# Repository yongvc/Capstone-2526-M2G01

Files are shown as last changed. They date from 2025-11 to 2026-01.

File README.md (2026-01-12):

# Lemon Harvesting Robot Capstone Project

This project contains the complete source code and design files for an autonomous lemon harvesting robot. The system uses computer vision to detect lemons and controls a 3-axis gantry robot to harvest them automatically.

## System Architecture

```
+------------------+     Serial (115200)     +------------------+
|    Dashboard     | <------------------->   |   ESP32 MCU      |
|  (Python + CV)   |                         |   (Firmware)     |
+--------+---------+                         +--------+---------+
         |                                            |
         v                                            v
+------------------+                         +------------------+
| - Camera Capture |                         | - TMC2209 x3     |
| - Lemon Detection|                         | - Servos x4      |
| - Kalman Tracking|                         | - LEDs x4        |
| - Visual Servo   |                         | - Soft Limits    |
| - Harvest State  |                         | - I/O Expansion  |
+------------------+                         +------------------+
```

## Directory Structure

- **[`Dashboard/`](./Dashboard)**: The main control software
    - Python-based GUI (CustomTkinter) with dark theme
    - Real-time Computer Vision (OpenCV) for lemon detection
    - Kalman filter tracking for smooth, jitter-resistant control
    - Visual servo control with closed-loop feedback
    - Multi-threaded camera capture at 30 FPS
    - Auto-harvest mode for consecutive fruit harvesting
    - Serial communication with the firmware

- **[`Motor_Controller_Firmware/`](./Motor_Controller_Firmware)**: ESP32 firmware
    - Non-blocking stepper motor control with TMC2209 drivers
    - Trapezoidal acceleration profiles for smooth motion
    - Servo control for cutter and gripper mechanisms
    - 16+ serial commands for complete robot control
    - LED status indicators and soft limit protection

- **[`CAD/`](./CAD)**: Mechanical design files
    - SolidWorks assembly and part files
    - 3-axis gantry robot design

- **[`PCB/`](./PCB)**: Electronics design
    - Printed Circuit Board designs for motor driver integration

- **[`Report/`](./Report)**: Project documentation
    - Individual progress reports
    - Technical documentation

## Key Features

### Computer Vision
- **HSV Color Segmentation**: Tuned for yellow lemon detection (H: 10-30, S: 70-255, V: 40-255)
- **Watershed Algorithm**: Separates touching/overlapping lemons
- **Kalman Filter Tracking**: Smooth position estimation with velocity prediction
- **Persistent Object IDs**: Maintains tracking across frames even during temporary occlusion

### Motion Control
- **Non-Blocking Movement**: Firmware responds to commands during motion
- **Multi-Axis Simultaneous Control**: X, Y, Z axes move together for smooth tracking
- **Visual Servo Control**: Closed-loop approach using camera feedback
- **Trapezoidal Acceleration**: Smooth start/stop for precise positioning

### Harvesting Automation
- **State Machine Control**: IDLE -> APPROACHING -> CUTTING -> DEPOSITING -> RETURNING
- **Auto-Harvest Mode**: Consecutively harvest multiple lemons (configurable count)
- **Dynamic Speed Control**: Fast when far, slow and precise when close
- **Cutter Alignment Offset**: Configurable offset to compensate for camera-cutter distance

### User Interface
- **Real-time Video Display**: Embedded OpenCV window for 60 FPS performance
- **Manual Control Panel**: Direct stepper and servo control
- **Target Selection**: Click to select which lemon to harvest
- **Status Indicators**: FPS display, harvest state, axis positions
- **Mock Mode**: Test with pre-recorded video without hardware

## Getting Started

### Prerequisites
- Python 3.8+ with pip
- Arduino IDE or PlatformIO (for firmware upload)
- ESP32 development board
- USB webcam (640x480 recommended)

### Running the Dashboard

1. Navigate to the `Dashboard` directory:
    ```bash
    cd Dashboard
    ```

2. Create and activate virtual environment:
    ```bash
    python -m venv venv
    # Windows:
    .\venv\Scripts\activate
    # Linux/Mac:
    source venv/bin/activate
    ```

3. Install dependencies:
    ```bash
    pip install -r requirements.txt
    ```

4. Run the application:
    ```bash
    python main.py
    ```

### Uploading Firmware

1. Open `Motor_Controller_Firmware/Motor_Controller_Firmware.ino` in Arduino IDE
2. Install required libraries:
   - TMC2209 (for stepper driver communication)
3. Select ESP32 board and correct COM port
4. Upload to the ESP32

### Hardware Setup

1. Connect ESP32 to computer via USB
2. Connect webcam
3. Power on motor drivers (12-24V)
4. In Dashboard, select COM port and click "Connect"
5. Use "Set Zero" to establish home position
6. Start detection and select target lemon
7. Click "HARVEST" or use "AUTO" mode

## Serial Command Protocol

| Command | Format | Description |
|---|---|---|
| M | `M <axis> <dist> <speed> <accel>` | Non-blocking move (mm) |
| B | `B <axis> <dist> <speed> <accel>` | Blocking move (mm) |
| ? | `?` | Query position and busy state |
| G | `G` | Get axis limits configuration |
| H | `H` | Set current position as zero |
| R | `R` | Release/unlock steppers |
| ! | `!` | Emergency stop |
| S | `S <index> <angle>` | Set servo angle |
| C | `C <angle>` | Execute cut sequence |
| D | `D <angle>` | Execute drop sequence |

## Performance

- **Camera Capture**: 30 FPS (640x480)
- **Detection Rate**: 25-30 FPS
- **Display Rate**: 60 FPS (native OpenCV)
- **Serial Latency**: <50ms round-trip
- **Tracking Recovery**: Up to 3 seconds occlusion tolerance (90 frames)

## Technical Specifications

| Component | Specification |
|---|---|
| **Axis Travel** | X: 130mm, Y: 230mm, Z: 130mm |
| **Max Speed** | 500 mm/s |
| **Max Acceleration** | 6000 mm/s² |
| **Steps per mm** | 40 |
| **Camera Resolution** | 640 x 480 @ 30 FPS |
| **Detection HSV** | H: 10-30, S: 70-255, V: 40-255 |
| **Kalman Filter** | process_noise=0.5, measurement_noise=1.0 |
| **Visual Servo Gain** | 0.10 mm/pixel |
| **Area Threshold** | 23000 px² (triggers cutting) |
| **Approach Threshold** | 25 px (alignment tolerance) |
| **Cutter Offset** | Z: 50mm, Y: 60mm |
| **Total Cost** | RM 608 |

## Authors

- **M2G01 Team** - UTM Capstone Project 2025/2026

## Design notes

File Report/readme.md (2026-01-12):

# Project Reports & Documentation

This directory contains project documentation and reports for the Lemon Harvesting Robot Capstone Project.

## Documents

| File | Description |
|---|---|
| `Technical_Report.txt` | Complete technical report with system design, implementation details, and team contributions |
| `Discussion Note (W1-W12).pdf` | Weekly discussion notes and meeting records |
| `Rules&RubricLime Harvesting Robot Challenge v9.pdf` | Competition rules and evaluation rubric |
| `System Block Diagram.png` | High-level system architecture diagram |

## Technical Report Summary

The Technical Report (`Technical_Report.txt`) contains:

1. **Introduction** - Problem statement and objectives
2. **Literature Review** - Existing solutions and market analysis
3. **Methodology** - CDIO framework and development approach
4. **System Design** - Hardware and software architecture
5. **Implementation** - Detailed component development
6. **Testing & Results** - Performance evaluation
7. **Future Works** - Planned improvements
8. **Conclusion** - Project outcomes and cost analysis
9. **Team Contributions** - Individual member contributions with code references

### Key Technical Specifications

| Parameter | Value |
|---|---|
| HSV Detection | H: 10-30, S: 70-255, V: 40-255 |
| Kalman Filter | process_noise=0.5, measurement_noise=1.0 |
| Area Threshold | 23000 px² |
| Visual Servo Gain | 0.10 mm/pixel |
| Axis Travel | X: 130mm, Y: 230mm, Z: 130mm |
| Max Speed | 500 mm/s |
| Steps per mm | 40 |
| Serial Baud | 115200 |
| Total Cost | RM 608 |

## Team Members

| Member | Responsibility |
|---|---|
| M1 - Yasser Ashraf | Vision System & Lemon Detection |
| M2 - Afifah Maisarah | User Interface & Dashboard |
| M3 - Chew Yong Jun | Mechanical Design & Assembly |
| M4 - Yong Vin Cent | Firmware & Motor Controller |

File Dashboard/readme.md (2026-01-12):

# Robot Dashboard

The Dashboard is the central control interface for the Lemon Harvesting Robot. It provides real-time camera visualization, computer vision-based lemon detection with Kalman tracking, and automated harvesting control through a visual servo system.

## Architecture

```
main.py (DashboardApp)
    |
    +-- camera.py
    |   +-- CameraThread      (30 FPS capture, triple-buffered)
    |   +-- DetectionThread   (async detection, Kalman tracking)
    |   +-- FrameBuffer       (zero-copy frame delivery)
    |
    +-- harvester.py
    |   +-- HarvestingStateMachine (visual servo control)
    |   +-- HarvestState enum (IDLE, APPROACHING, CUTTING, DEPOSITING, RETURNING)
    |
    +-- embedded_cv_display.py
    |   +-- EmbeddedCVDisplay (native OpenCV in Tkinter)
    |
    +-- LemonDetector/
        +-- detect.py         (HSV + Watershed detection)
        +-- kalman_tracker.py (Kalman filter tracking)
```

## Features

### Real-time Computer Vision
- **HSV Color Segmentation**: Optimized for yellow lemon detection
- **Watershed Algorithm**: Separates touching/overlapping fruits
- **Multi-Object Tracking**: Persistent IDs across frames
- **Kalman Filter Smoothing**: Reduces jitter, predicts during occlusion

### Visual Servo Control
- **Closed-Loop Approach**: Uses camera feedback for alignment
- **Multi-Axis Simultaneous Movement**: X, Y, Z move together for smooth tracking
- **Dynamic Speed Control**: Fast when far, slow when close for precision
- **Area-Based Distance Estimation**: Triggers cutting when lemon is close enough

### Harvesting Automation
- **Single Target Mode**: Select and harvest one lemon
- **Auto-Harvest Mode**: Consecutively harvest 3 lemons (configurable)
- **State Machine**: IDLE -> APPROACHING -> CUTTING -> DEPOSITING -> RETURNING
- **Jitter Tolerance**: Maintains tracking during camera vibration (up to 3s occlusion)

### User Interface
- **Dark Theme**: Modern CustomTkinter interface
- **Embedded Video Display**: Native OpenCV rendering at 60 FPS
- **Manual Controls**: Direct stepper and servo control
- **Status Display**: FPS, harvest state, detected lemons list
- **Center Offset**: Calibrate cutter position relative to camera

## Module Documentation

### main.py - DashboardApp

The main application class that integrates all components:

```python
class DashboardApp(ctk.CTk):
    def __init__(self):
        # Initialize camera and detection threads
        self.camera_thread = CameraThread(mock_mode=False, target_fps=30)
        self.detection_thread = DetectionThread(self.camera_thread.frame_buffer)
        
        # Initialize harvesting state machine
        self.harvester = HarvestingStateMachine(self)
        
        # Setup UI components
        self.setup_controls()
```

Key methods:
- `toggle_connection()`: Connect/disconnect serial port
- `update_camera_ui()`: Main UI update loop (33ms interval)
- `start_harvest()`: Begin harvesting selected lemon
- `start_auto_harvest()`: Begin auto-harvest mode
- `send_command(cmd)`: Send command to firmware

### camera.py - Multi-Threaded Capture

**CameraThread**: Captures frames at target FPS
```python
class CameraThread(threading.Thread):
    def __init__(self, mock_mode=False, mock_path="mock_lemon.mp4", target_fps=30):
        self.frame_buffer = FrameBuffer()  # Triple-buffered output
```

**DetectionThread**: Runs detection asynchronously
```python
class DetectionThread(threading.Thread):
    def __init__(self, frame_buffer):
        self.detector = LemonDetector(use_kalman=True, responsive_tracking=True)
    
    def get_latest(self):
        return self._latest_frame, list(self._latest_lemons)
```

**FrameBuffer**: Zero-copy frame delivery
```python
class FrameBuffer:
    def write(self, frame): # Producer (camera thread)
    def read(self):         # Consumer (detection thread)
    def wait_for_frame(self, timeout=0.1):
```

### harvester.py - Harvesting State Machine

Visual servo control with multi-axis simultaneous movement:

```python
class HarvestingStateMachine:
    # Key parameters (tunable)
    self.area_threshold = 23000       # pixels^2 to trigger cutting
    self.approach_threshold = 25      # pixels alignment tolerance
    self.visual_servo_gain = 0.10     # mm per pixel error
    self.forward_speed = 20.0         # mm per forward step
    self.max_correction = 15.0        # max mm per correction
    self._max_frames_lost = 90        # 3 seconds at 30fps before abort
    
    # Speed settings
    self.approach_speed = 30          # mm/s for X/Z corrections
    self.forward_approach_speed = 80  # mm/s for Y forward
    self.fast_speed = 200             # mm/s for deposit/return
    
    # Cutter offsets
    self.cutting_z_offset = 50        # mm (cutter below camera)
    self.cutting_y_offset = 60        # mm (cutter behind camera)
```

State transitions:
1. **IDLE**: Waiting for harvest command
2. **APPROACHING**: Visual servo approach using Kalman-smoothed positions
3. **CUTTING**: Move to cutter offset, execute cut sequence
4. **DEPOSITING**: Move to basket, execute drop sequence
5. **RETURNING**: Return to home position

### LemonDetector/detect.py - Detection Pipeline

HSV + Watershed detection with tracking:

```python
class LemonDetector:
    # HSV ranges (tuned for yellow lemons)
    FIXED_H_MIN, FIXED_H_MAX = 10, 30
    FIXED_S_MIN, FIXED_S_MAX = 70, 255
    FIXED_V_MIN, FIXED_V_MAX = 40, 255
    
    # Tracking parameters
    self.maxDisappeared = 1000        # frames before deregistering
    self.maxMatchDistance = 300       # pixels for ID matching
```

Detection pipeline:
1. Gaussian blur (11x11)
2. HSV color thresholding
3. Morphological opening + dilation
4. Distance transform + watershed
5. Contour analysis (filter by area > 1000, circularity > 0.3)
6. Multi-object tracking with Kalman filtering

### LemonDetector/kalman_tracker.py - Smooth Tracking

Constant velocity Kalman filter for each tracked object:

```python
class KalmanTracker:
    # State: [x, y, vx, vy]
    # Responsive mode: process_noise=0.5, measurement_noise=1.0
    
    def predict(self):      # Predict next position
    def update(self, pos):  # Correct with measurement
    def get_position(self): # Get smoothed position
    def get_velocity(self): # Get velocity estimate
```

Benefits:
- Smooths detection jitter from camera vibration
- Predicts position during temporary occlusion (up to 60 frames / 2s in Kalman, 90 frames / 3s in harvester)
- Provides velocity for predictive control

### embedded_cv_display.py - Native OpenCV Display

Embeds OpenCV window inside Tkinter for native rendering performance:

```python
class EmbeddedCVDisplay:
    def _create_and_embed(self):
        # Create OpenCV window
        cv2.namedWindow(self.window_name, cv2.WINDOW_NORMAL)
        
        # Reparent using Windows API
        win32gui.SetParent(self.cv_hwnd, tk_hwnd)
    
    def update(self, frame):
        cv2.imshow(self.window_name, frame)  # Native rendering
```

Performance: ~60 FPS vs ~15 FPS with PIL/ImageTk conversion.

## Setup

1. Navigate to this directory:
    ```bash
    cd Dashboard
    ```

2. Create virtual environment:
    ```bash
    python -m venv venv
    .\venv\Scripts\activate  # Windows
    ```

3. Install dependencies:
    ```bash
    pip install -r requirements.txt
    ```

## Usage

Run the main application:
```bash
python main.py
```

### Controls

| Control | Description |
|---|---|
| Connect | Connect to ESP32 via serial port |
| HARVEST | Harvest the selected (highlighted) lemon |
| AUTO (3) | Automatically harvest 3 lemons consecutively |
| ABORT | Stop current harvest and return home |
| Move | Move selected axis by distance/speed/accel |
| Center | Move all axes to home position |
| Set Zero | Set current position as 0,0,0 |
| Unlock | Disable steppers for manual movement |
| Cut/Drop | Test cutter and gripper mechanisms |
| EMERGENCY STOP | Immediately stop all motors |

### Tuning Detection

For different lighting conditions, adjust HSV values in `LemonDetector/detect.py`:
```python
self.FIXED_H_MIN = 10   # Hue minimum (yellow starts ~10)
self.FIXED_H_MAX = 30   # Hue maximum (yellow ends ~35)
self.FIXED_S_MIN = 70   # Saturation minimum (filter out white)
self.FIXED_V_MIN = 40   # Value minimum (filter out dark)
```

Enable tuning mode to use trackbars:
```python
detector = LemonDetector(tuning_mode=True)
```

### Calibrating Center Offset

The cutter is physically offset from the camera. Use the Offset X/Y controls to compensate:
1. Position a lemon at the camera center (crosshair)
2. Observe where the cutter actually aligns
3. Enter offset values to shift the target point
4. Click "Apply" to update

## Key Files

| File | Description |
|---|---|
| `main.py` | Main application, UI, serial communication |
| `camera.py` | Multi-threaded camera capture and detection |
| `harvester.py` | Harvesting state machine, visual servo control |
| `embedded_cv_display.py` | Native OpenCV window embedding |
| `LemonDetector/detect.py` | Computer vision detection pipeline |
| `LemonDetector/kalman_tracker.py` | Kalman filter for smooth tracking |
| `mock_lemon.mp4` | Sample video for Mock Mode testing |
| `requirements.txt` | Python dependencies |

## Dependencies

- `customtkinter` - Modern Tkinter widgets
- `opencv-python` - Computer vision
- `numpy` - Numerical operations
- `pyserial` - Serial communication
- `pywin32` - Windows API for embedded display (Windows only)

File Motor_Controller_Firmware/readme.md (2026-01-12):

# Motor Controller Firmware

This directory contains the ESP32 firmware for the robot's motor controller. It provides non-blocking stepper motor control with TMC2209 drivers, servo control for the harvesting mechanism, and a comprehensive serial command protocol.

## Architecture

```
Motor_Controller_Firmware.ino (Main Loop)
    |
    +-- StepperController.cpp/h
    |   - Non-blocking movement with trapezoidal acceleration
    |   - TMC2209 UART driver control
    |   - Position tracking in mm (40 steps/mm)
    |   - Soft limits with min/max per axis
    |   - Move completion detection (checkCompleted)
    |
    +-- ServoController.cpp/h
    |   - PWM control for 4 servos
    |   - Angle-based positioning (0-180 degrees)
    |   - Used for cutter (servos 0,1) and gripper (servo 2)
    |
    +-- LEDController.cpp/h
    |   - 4 status LEDs with non-blocking blink
    |   - LED 0: Heartbeat, LED 1: Moving, LED 2: Home, LED 3: Limit warning
    |
    +-- IOController.cpp/h
    |   - Digital input reading
    |   - Reserved for limit switch inputs (optional hardware)
    |
    +-- Config.h
    |   - Serial baud rate, timing constants
    |
    +-- PinMap.h
        - Pin assignments for ESP32
```

## Features

### Non-Blocking Motor Control
- Motors move without blocking serial command processing
- `M` command returns immediately, firmware sends `DONE <axis>` when complete
- Enables visual servo control with real-time position updates

### Trapezoidal Acceleration
- Smooth acceleration/deceleration profiles
- Configurable max speed (500 mm/s) and acceleration (6000 mm/s^2)
- Per-axis motion state tracking

### Soft Limits (Software-Based)
- Configurable min/max limits per axis
- Prevents over-travel using software position tracking
- No physical limit switches required (optional hardware)
- Limits sent to Dashboard via `G` command

### LED Status Indicators
| LED | Function |
|-----|---|
| 0 | Heartbeat (continuous blink) |
| 1 | Moving (ON when any axis active) |
| 2 | Home (ON when all axes at 0,0,0) |
| 3 | Limit warning (fast blink when at limit) |

## Serial Command Protocol

**Baud Rate**: 115200

### Motor Commands

| Command | Format | Response | Description |
|---|---|---|---|
| M | `M <axis> <dist> <speed> <accel>` | `OK M` then `DONE <axis>` | Non-blocking move |
| B | `B <axis> <dist> <speed> <accel>` | `BUSY M` then `DONE <axis>` | Blocking move |
| ? | `?` | `POS x y z` + `BUSY 0 0 0` | Query position/status |
| G | `G` | `LIMITS x y z` | Get axis limits |
| H | `H` | `OK H` | Set current position as 0,0,0 |
| R | `R` | `OK R` | Release/unlock steppers |
| P | `P <axis> <pos>` | `OK P` | Set axis position value |
| W | `W <axis> <min> <max>` | `OK W` | Set soft limits |
| E | `E <0\|1>` | `OK E` | Enable/disable limits |
| ! | `!` | `STOP` | Emergency stop all axes |

### Servo Commands

| Command | Format | Response | Description |
|---|---|---|---|
| S | `S <index> <angle>` | `OK S` | Set servo angle (0-180) |
| C | `C <angle>` | `BUSY C` then `OK C` | Cut sequence (servos 0,1) |
| D | `D <angle>` | `BUSY D` then `OK D` | Drop sequence (servo 2) |

### Utility Commands

| Command | Format | Response | Description |
|---|---|---|---|
| L | `L <index> <state>` | `OK L` | Control LED on/off |
| I | `I <index>` | `IO <index> <val>` | Read digital input |
| Z | `Z <axis>` | `LIMIT <axis> <val>` | Read limit switch (optional) |

### Axis Numbering
- 0 = X axis (left-right)
- 1 = Y axis (forward-backward)  
- 2 = Z axis (up-down)

### Response Messages
- `OK <cmd>` - Command accepted
- `BUSY <cmd>` - Command in progress (blocking)
- `DONE <axis>` - Movement complete on axis
- `STOP` - Emergency stop executed
- `POS x y z` - Current position in mm
- `BUSY 0 0 0` - Busy state per axis (0=idle, 1=moving)
- `LIMITS x y z` - Max limits per axis in mm

## Cut Sequence Details

The `C <angle>` command executes a triple-cut sequence:
1. Servos 0,1 move to scissor position (90-angle, 90+angle)
2. Wait 300ms
3. Return to neutral (90, 90)
4. Repeat 3 times for reliable cutting
5. Send `OK C`

## Drop Sequence Details

The `D <angle>` command executes:
1. Servo 2 moves to release position (90-angle)
2. Wait 1000ms for fruit to fall
3. Return to neutral (90)
4. Send `OK D`

## Configuration

### StepperController.h Constants
```cpp
static constexpr float STEPS_PER_MM = 40.0;      // Steps per millimeter
static constexpr float MAX_SPEED_MM_S = 500.0;   // Max speed mm/s
static constexpr float MAX_ACCEL_MM_S2 = 6000.0; // Max acceleration mm/s^2
```

### Default Axis Limits
- X: 0 to 130 mm
- Y: 0 to 230 mm
- Z: 0 to 130 mm

## Setup

1. Open `Motor_Controller_Firmware.ino` in Arduino IDE

2. Install required libraries:
   - **TMC2209** (for stepper driver UART control)

3. Select board:
   - Board: ESP32 Dev Module (or your specific ESP32 variant)
   - Upload Speed: 921600
   - CPU Frequency: 240MHz

4. Upload the firmware

5. Open Serial Monitor at 115200 baud to test:
   ```
   G           # Get limits
   ?           # Query position
   M 0 50 100 200   # Move X axis 50mm
   ```

## Pin Configuration

### GPIO Assignments (from PinMap.h)

| Function | GPIO Pins |
|---|---|
| **LEDs** | 39, 40, 41, 42 |
| **Servos** | 9, 10, 11, 12 |
| **Stepper Enable** | 20 (shared, active-LOW) |
| **X-axis** | Step: 8, Dir: 18 |
| **Y-axis** | Step: 17, Dir: 16 |
| **Z-axis** | Step: 15, Dir: 7 |
| **TMC2209 UART** | RX: 2, TX: 1 |
| **Digital I/O** | 13, 14, 21, 47, 48 |

### Config.h Constants

| Parameter | Value |
|---|---|
| Serial Baud Rate | 115200 |
| TMC2209 R_SENSE | 0.11 ohms |
| Servo PWM Min | 500 us |
| Servo PWM Max | 2400 us |
| LED Blink Interval | 500 ms |

## Integration with Dashboard

The Dashboard Python application communicates with this firmware:

1. Dashboard connects to COM port at 115200 baud
2. Queries configuration: `G` command
3. Queries position: `?` command  
4. Sends move commands: `M <axis> <dist> <speed> <accel>`
5. Waits for `DONE <axis>` response
6. Executes cut/drop sequences: `C <angle>`, `D <angle>`

The non-blocking `M` command allows the Dashboard to send corrective movements during visual servo approach without waiting for previous moves to complete.

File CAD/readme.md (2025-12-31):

# Mechanical Design (CAD)

This directory contains the SolidWorks (`.SLDPRT`, `.SLDASM`) files for the Lemon Harvesting Robot.

## Structure

The main assembly file is located in `final assembly 1/`:
- **Main Assembly**: `final assembly 1.SLDASM`

### Key Components
- **Arm Mechanism**: `Arm.SLDASM` - The robotic arm structure for connecting the chassis to the end effector.
- **End Effector/Gripper**:
    - `CutterHolder.SLDPRT`
    - `UScissor.SLDPRT`
    - `ServoScissorHolder.SLDPRT`
- **Chassis/Base**: `Base.SLDPRT`, `Cam Base.SLDPRT`
- **Drive System**: Stepper motors (`Assem1_stepper_motor.SLDASM`), pulleys, and belts.
- **Camera Mount**: `Camera Casing.SLDPRT`, `C260 WebCam Assembly.SLDASM`

## Usage
Open `final assembly 1/final assembly 1.SLDASM` in SolidWorks to view the complete robot assembly.

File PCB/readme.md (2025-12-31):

# PCB Design

This directory contains the files related to the custom Printed Circuit Board (PCB) designed for the robot.

## Contents
- **Gerber Files**: `Capstone Agriculture Gerber_PCB1_2025-11-11.zip` - The production files to send to a PCB manufacturer (e.g., JLCPCB).
- **Interactive BOM**: `InteractiveBOM_PCB1_2025-11-29.html` - An interactive HTML file to assist with component placement and soldering. Open this in a web browser.
- **Schematic**: `SCH_Schematic1_1-P1_2025-11-21.png` - Image of the circuit schematic.

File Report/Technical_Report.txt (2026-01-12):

Automated Lemon Harvesting Robot

Yasser Ashraf Aly Abdelsattar Youssef, Afifah Maisarah binti Asmadi, Chew Yong Jun, Yong Vin Cent, Tn Hj Mohd Shukri Abdul Manaf
Universiti Teknologi Malaysia, Malaysia

================================================================================
ABSTRACT
================================================================================

The agricultural industry faces increasing challenges due to labor shortages and the need for precision in fruit harvesting, particularly for citrus crops like lemons which require careful handling. This project addresses these challenges through the development of an automated lemon harvesting robot designed to autonomously identify, reach, and collect ripe fruit. The system utilizes a three-axis (XYZ) linear slider mechanism driven by NEMA 17 stepper motors and timing belts for precise spatial positioning. At the core of the hardware is a customized PCB integrating an ESP32 microcontroller, buck converters, stepper motor drivers, and servo controllers to manage power and motion. For fruit identification, the system employs an OpenCV-based computer vision algorithm that performs color segmentation and coordinate detection to distinguish ripe lemons from the canopy. Once a target is identified, a central Python script orchestrates the harvesting sequence, calculating trajectories and transmitting specific motion commands to the embedded controller. The controller then maneuvers a specialized end-effector to cut and catch the lemon before placing it into a collection basket. A dedicated user interface provides real-time monitoring of lemon ripeness, lemon positions, and system status. Preliminary results indicate a fruit detection success rate of 90% and a positioning accuracy of within 10mm. This study demonstrates that low-cost, high-precision robotics can effectively digitize orchard management, offering a scalable solution to agricultural labor shortages and improving overall harvest yield.

Keywords: Agricultural Robotics, Computer Vision, Automated Harvesting, ESP32 Microcontroller, Precision Agriculture

================================================================================
1. CONCEIVE
================================================================================

1.1 Background Introduction

The target users for this project are fruit farmers, especially those who grow citrus fruits like lemons. These farmers face many problems when it comes to harvesting their crops.

The first major problem is shortage of workers. Farm work is tiring and the harvesting season only lasts for a few months each year. This makes it hard to find people who want to do this job. Big farms sometimes need 50 to 60 workers just to harvest all the fruit, which costs a lot of money.

Another problem is worker safety. The traditional way of picking fruit involves climbing up ladders to reach fruit on tall trees. Workers can fall and get injured. New workers who do not have experience often damage the fruit because they do not know the proper way to handle it.

The quality of harvest is also affected by using manual labour. How good the harvest turns out depends on how skilled the worker is. When workers use gloves and clippers, they may not cut the stem at the right place or they may squeeze the fruit too hard. This damages the fruit and makes it harder to sell.

Lastly, the whole harvesting process is still done by hand, from picking the fruit to sorting them by quality. This takes a lot of time and the farm cannot process as many fruit as they could with machines.

These problems show why there is a need for a robot that can find ripe fruit, reach it accurately, and pick it without causing damage. This would help farmers save money on workers and get better quality fruit.

1.2 End-user Input Data

To understand what farmers really need, our team prepared a questionnaire and interviewed real farmers. We asked the following questions:

1. How do you currently harvest fruits or crops from the trees?
2. What are the biggest challenges or difficulties you face during harvesting?
3. Which part of the harvesting process takes the most time or effort?
4. Are there any safety or injury risks that come with harvesting?
5. How many workers are usually needed to harvest one tree or a section of the farm?
6. Have you ever tried or seen harvesting machines or tools before? If yes, what did you like or dislike about them?
7. What features would be most valuable to you in a harvesting solution?
8. What kind of terrain and tree height should the solution be able to handle?
9. How much are you willing to invest or spend on technology that can make harvesting easier or faster?
10. Would you be open to testing or giving feedback on a prototype harvesting solution?

We conducted interviews with several farmers and plant sellers. From these discussions, each team member extracted key data points.

Yasser found that farmers are interested in features like camera systems for fruit counting, smart sensors to detect fruit size and colour, lightweight harvesting robot arms, and drone monitoring for crop health.

Chew Yong Jun learned that farmers use equipment with cameras, pruners and nets. They face challenges with labour availability and weather. There is interest in automated ripeness detection based on colour, firmness, and average fruit size. Some farms use open fertigation systems with IoT integration.

Vin Cent discovered that harvesting is done manually with gloves and clippers. The main challenges are labour availability and weather. Farms need 50 to 60 workers. There are risks of falling from ladders and inexperienced workers damaging crops. Previous harvesting machines were not cost effective. The terrain is flat but sandy and muddy, with plants up to 10 feet tall. Farmers are open to cost-effective solutions and willing to allow farm visits for testing.

Afifah found that farmers want better control and better cutters. Ripeness is judged based on colours, firmness, and good sizes. They track planting days (Hari Selepas Tanam) and harvest rate per hour. They need a catcher or net to maintain fruit shape. Challenges include labour shortage and weather dependency. Harvesting starts early in the morning for quality.

1.3 User Needs Analysis

Based on what we learned from the interviews, we grouped all the data into six categories using data clustering.

The first category is Automation and Control. This includes automated ripeness detection based on colour, firmness and size. It also includes timing control for when to harvest and systems for predicting labour needs.

The second category is Sensing and Vision. This includes machine vision for counting fruit, smart sensors to detect fruit size and colour, IoT systems with sensors that connect to computers, and weather sensors.

The third category is Monitoring. This includes drone monitoring for checking crop health, drone mapping to find ripe areas, and remote dashboards so farmers can check farm status from anywhere. Some farms want Starlink internet for stable connectivity.

The fourth category is Harvesting Systems. This includes lightweight harvesting robot arms, automated harvesting combined with sorting and grading, catcher or net systems to maintain fruit shape, and improved cutters.

The fifth category is Farm Management. This includes tracking harvesting rate per hour, open fertigation systems, tracking of planting dates, and open farm systems that work in outdoor environments. Farms want on-site visits for testing and validation.

The sixth category is Challenges and Constraints. This includes labour availability problems where farms need 50 to 60 workers. Manual harvesting and grading is slow. There are injuries from falling off ladders and from inexperienced workers. Weather affects work because of rain and heat. The terrain is flat but sandy and muddy. Past harvesting machines were not cost effective. Harvesting needs to start early in the morning for quality.

1.4 Personification and Design Statement

We created a persona to represent our target users. His name is Pak Rahman. He is 55 years old and is an experienced farmer. He owns a medium-sized fruit farm of 5 acres. He has 30 years of farming experience but uses traditional methods and has limited knowledge about technology.

Pak Rahman faces several problems. He has a shortage of workers and high worker turnover. The weather is unpredictable and often disrupts his harvest. He has difficulty identifying which fruits are ripe accurately.

What Pak Rahman needs is easy-to-use automated tools that work like plug-and-play. He wants reliable weather and ripeness alerts. He needs affordable harvesting solutions. He also needs local support and training for any new technologies he uses.

Our design statement is: How might we help Pak Rahman to harvest effectively despite labour shortages by providing efficient, consistent, and affordable automation tools that adapt to his existing workflow?

1.5 Idea Generation

Our team spent time thinking of different ways to solve this problem.

The first idea was to pull the fruit slightly before cutting. This would move the stem to a position where it is easier to cut. However, we did not choose this because pulling the fruit might bruise it.

The second idea was to use suction to hold the fruit while cutting. This is like a vacuum cleaner that holds the fruit. We did not choose this because the mechanism is complicated and might still damage the fruit.

The third idea was to use a camera to see where the stem is and cut it precisely without touching the fruit. We chose this idea because it causes the least damage to the fruit and relies on accurate positioning instead of grabbing.

The fourth idea was to use a robot arm like in factories to grab and twist the fruit off. We did not choose this because robot arms are very expensive and hard to control.

We chose our ideas based on whether we could actually build them with what we have, whether they solve the farmer's needs, how much they cost, and whether the technology is proven to work.

Our final design is a robot that moves in three directions (X, Y, and Z) using a camera to detect lemons. It positions a scissor-type cutter at the stem and cuts without touching the fruit. A gripper catches the fruit and puts it into a basket.

1.6 Conceptual Prototype Development

We built our prototype in several stages.

In the first stage, we designed the mechanical frame. We used SolidWorks software to draw a XYZ sliding system. We picked NEMA 17 stepper motors with timing belts to move each axis. The frame is made from aluminium pieces that can be adjusted.

In the second stage, we designed the cutting mechanism. We used thread U-shape scissors that are moved by MG90S servo motors. There are two servos that close the scissors like a pinching motion. There is also a gripper to catch the fruit after it is cut.

In the third stage, we planned the vision system. We use a USB webcam to see the lemons. A computer program written using OpenCV library looks at the colours in the image to find yellow lemons. The program tells the motors where to move.

In the fourth stage, we designed the control system. We made a custom circuit board with an ESP32 chip as the brain. This board has TMC2209 chips to control the stepper motors. It receives commands through a USB cable from a computer.

In the fifth stage, we built the user interface. This is a program on the computer that shows the camera view and lets the user control the robot. It was made using Python with a library called CustomTkinter.

1.7 STEEP Analysis and SDG Requirements

We looked at how our project affects different parts of society.

TABLE I: STEEP Analysis Summary

| Aspect | Contribution |
|---|---|
| Social | Reduces physical labour requirements, leading to fewer ladder injuries and enabling elderly farmers to continue working. |
| Technological | Democratizes precision agriculture through low-cost robotics accessible to small farms. |
| Economic | Reduces labour costs by 60-70% with ROI within 2-3 harvest seasons. |
| Environmental | Reduces food waste from damaged fruit using electric motors with no emissions. |
| Political | Aligns with National Agrofood Policy 2021 and supports food security goals. |

Social Impact:
For society, our robot reduces the need for physical labour. This means fewer workers will get injured from falling off ladders. Older farmers who cannot do heavy work anymore can still run their farms with help from the robot. The robot works consistently regardless of weather or worker availability.

Technological Impact:
For technology, our project shows how cameras, electronics, and motors can work together for farming. This kind of technology was previously only available to big companies, but we made it affordable for small farms. The open-source design allows others to replicate and improve it.

Economic Impact:
For the economy, our robot can reduce labour costs because farmers do not need to hire as many workers. A farmer could get back the money spent on the robot within 2 to 3 harvest seasons. This also creates new jobs for people who maintain and repair the robots. The cost of RM 608 is approximately 380 times cheaper than commercial alternatives.

Environmental Impact:
For the environment, picking fruit carefully means less fruit gets damaged and thrown away. The electric motors do not produce exhaust fumes. The robot uses less energy than big farm machines. Reduced food waste contributes to sustainability goals.

Political Impact:
For politics, our project fits with Malaysia's National Agrofood Policy which encourages farmers to use new technology. It also helps with food security by making harvesting more efficient.

UN Sustainable Development Goals (SDG) Contributions:

| SDG | Goal Name | Contribution |
|---|---|---|
| SDG 2 | Zero Hunger | Reduces post-harvest losses by 10-15% |
| SDG 8 | Decent Work | Eliminates dangerous ladder work |
| SDG 9 | Industry and Innovation | Develops affordable agricultural technology |
| SDG 12| Responsible Production | Minimizes fruit waste and resource usage |

Our project also supports the United Nations goals for sustainable development. It helps with Goal 2 (Zero Hunger) by reducing wasted fruit. It helps with Goal 8 (Decent Work) by reducing dangerous jobs. It helps with Goal 9 (Industry and Innovation) by developing technology for farms. It helps with Goal 12 (Responsible Production) by reducing waste.

1.8 Innovative Features

Our robot has several features that make it different from other products.

First, it does not touch the fruit. Most other robots grab the fruit to pick it. Our robot only cuts the stem, so the fruit does not get squeezed or bruised.

Second, it is very cheap. All the parts cost less than RM 2000. Other harvesting robots cost RM 50,000 or more. This makes our robot affordable for small farmers.

Third, the design is modular. The ESP32 controller uses simple text commands to move. This means different vision programs or control software can be used with the same hardware.

Fourth, the robot adjusts its position while approaching the fruit. The camera keeps watching the lemon and the robot corrects its path if the lemon moves or if the first detection was not accurate.

Fifth, we use two servos for cutting. This gives a stronger cut and the scissors can also hold the fruit after cutting so it does not fall.

================================================================================
2. DESIGN
================================================================================

2.1 System Architecture

Our robot system has three main parts that work together.

The first part is the user interface on a computer. This is a Python program that shows the camera view on screen. The user can see where the lemons are and control the robot from here. The program also shows messages about what the robot is doing.

The second part is the ESP32 controller. This is the brain of the robot. It receives commands from the computer through a USB cable. When it gets a command like "move X axis 50mm", it controls the motors to make that movement happen. It also controls the servos that operate the cutter.

The third part is the hardware. This includes the stepper motors that move the XYZ axes, the servo motors that operate the cutter and gripper, the webcam that sees the fruit, and LEDs that show the status of the robot.

The computer sends commands to the ESP32 through a serial connection. The ESP32 then sends electrical signals to the motors to make them move. The camera connects directly to the computer for image processing.

Software Architecture Diagram:

+--------------------------------------------------+
|              Python Dashboard (main.py)           |
|  +----------------+  +-----------------------+   |
|  | CameraThread   |  | DetectionThread       |   |
|  | - Frame capture|  | - LemonDetector       |   |
|  | - 30 FPS       |  | - HSV segmentation    |   |
|  | - DirectShow   |  | - Watershed algorithm |   |
|  +-------+--------+  | - Kalman tracking     |   |
|          |           +-----------+-----------+   |
|          v                       v               |
|  +----------------------------------------------+|
|  |    FrameBuffer (Triple-buffered)             ||
|  +----------------------------------------------+|
|          |                       |               |
|  +-------v-----------------------v--------------+|
|  |            DashboardApp (GUI)                ||
|  | - EmbeddedCVDisplay (native OpenCV rendering)||
|  | - Control panels    - Status logging         ||
|  | - Serial polling    - Target selection       ||
|  +-------------------+--+-----------------------+|
|                      |  |                        |
|  +-------------------v--v-----------------------+|
|  |      HarvestingStateMachine (harvester.py)   ||
|  | States: IDLE->APPROACHING->CUTTING->         ||
|  |         DEPOSITING->RETURNING->IDLE          ||
|  | Features:                                    ||
|  | - Multi-axis simultaneous control            ||
|  | - Visual servo with Kalman smoothing         ||
|  | - Auto-harvest mode (consecutive targets)    ||
|  +-------------------+--------------------------+|
+---------------------|----------------------------+
                      | Serial (115200 baud)
                      v
+--------------------------------------------------+
|           ESP32 Firmware (Motor_Controller)       |
|  +----------------+  +-------------------------+ |
|  |StepperController| |ServoController         | |
|  |- Non-blocking  | |- 4 PWM channels         | |
|  |- 3 axes (XYZ)  | |- Cutter and gripper     | |
|  |- TMC2209 UART  | |- 500-2400us PWM range   | |
|  |- Soft limits   | |                         | |
|  +-------+--------+ +------------+------------+ |
|          |                       |              |
|  +-------v-----------------------v------------+ |
|  |        Hardware Abstraction Layer          | |
|  | LEDController | IOController | Config.h    | |
|  +------------------------------------------------+
|                      |                          |
+----------------------|---------------------------+
                       v
+--------------------------------------------------+
|                    Hardware                       |
|  +-----------+  +-----------+  +---------------+ |
|  |TMC2209 x3 |  |MG90S x4   |  |USB Webcam     | |
|  |Stepper    |  |Servo      |  |640x480 30fps  | |
|  |Drivers    |  |Motors     |  |               | |
|  +-----------+  +-----------+  +---------------+ |
|  +-----------+  +-----------+                    |
|  |NEMA17 x3  |  |LEDs x4    |                    |
|  |Stepper    |  |Status     |                    |
|  |Motors     |  |Indicators |                    |
|  +-----------+  +-----------+                    |
+--------------------------------------------------+

Communication Protocol:

The system uses USB-to-UART serial communication at 115200 baud for reliable data transfer between the computer and ESP32 microcontroller. Commands follow a simple text-based format consisting of a single character command identifier followed by space-separated numerical parameters and terminated with a newline character. The firmware responds with acknowledgment messages such as "OK" for immediate commands, "BUSY" for blocking operations, and "DONE" upon movement completion. To prevent command loss during rapid communication, the serial buffer clearing routine was designed to preserve queued commands by only clearing characters up to the newline delimiter.

2.2 Flowchart for Coding

The main program follows these steps to harvest a lemon.

First, the system starts up and waits for a connection. When the user connects, the camera turns on and starts looking for lemons.

The detection algorithm looks at each frame from the camera. It converts the image to HSV colour space and looks for yellow colours. When it finds something yellow and round, it marks it as a lemon.

If no lemons are found, the system waits and keeps looking. If lemons are found, the system picks the one closest to the centre of the camera view.

The robot then checks if the lemon is centred in the camera. If the lemon is too far to the left or right, the robot moves the X axis to centre it. If the lemon is too high or low, the robot moves the Z axis to centre it.

Once the lemon is centred, the robot checks if it is close enough. It does this by looking at how big the lemon appears in the image. A bigger image means the lemon is closer. If the lemon is not close enough, the robot moves forward on the Y axis.

When the lemon is centred and close enough, the robot starts the cutting sequence. It moves the Z axis up to position the cutter at the stem. Then it moves the Y axis forward to put the cutter around the stem. Then it closes the scissors to cut.

After cutting, the robot retracts back. It moves the Z axis down and the Y axis back. Then it moves to the basket position, opens the gripper to drop the fruit, and returns to the home position. The harvest is complete.

2.3 Electrical Circuit Schematic

The electrical system has several parts.

For power, we use a 12V power supply. This goes to two buck converters. One converter changes 12V to 5V for the servos and ESP32. The other converter changes 12V to 3.3V for the logic circuits. The buck converters need specific capacitors to work correctly. We learned that the boot capacitor must be 10nF, not 10uF.

For motor control, we use three TMC2209 stepper driver chips. These chips make the motors move smoothly and quietly. Each driver has step and direction pins that connect to the ESP32. There is also an enable pin that must be set LOW for the motors to work.

For servo control, the ESP32 sends PWM signals to four servo motors. These servos control the cutter blades and gripper. The PWM range is configured as 500-2400 microseconds (Config.h:12-13).

The ESP32 also connects to four LEDs that show status. One LED blinks to show the system is running. Another LED turns on when motors are moving. Another LED shows when the robot is at the home position. The last LED blinks fast if there is a problem.

The ESP32 microcontroller pin assignments are defined in PinMap.h for maintainability and ease of modification. The status LEDs are connected to GPIO pins 39, 40, 41, and 42, providing visual feedback during operation. The four servo PWM outputs utilise GPIO pins 9, 10, 11, and 12 for controlling the cutter and gripper mechanisms. All three stepper motor drivers share a common enable signal on GPIO 20, which must be driven LOW to activate the motors. The X-axis stepper motor uses GPIO 8 for step pulses and GPIO 18 for direction control. The Y-axis stepper is controlled through GPIO 17 for stepping and GPIO 16 for direction. The Z-axis stepper utilises GPIO 15 for step pulses and GPIO 7 for direction. The TMC2209 drivers operate in legacy step/direction mode rather than UART mode, simplifying the control interface. Additional GPIO pins 13, 14, 21, 47, and 48 are reserved for future expansion and digital input/output capabilities.

The TMC2209 stepper drivers are configured in standalone mode with automatic StealthChop detection for quiet operation. The microstepping resolution is set to 1/8 step through hardware configuration using board jumpers, providing a balance between positioning resolution and motor torque. The step and direction interface allows direct control from the ESP32 GPIO pins without requiring UART communication, reducing firmware complexity while maintaining smooth motor operation.

2.4 Printed Circuit Board Layout

We designed a custom PCB using EasyEDA software. The board is 100mm by 80mm with copper on both sides.

The ESP32 module is placed in the centre of the board where it is easy to access for programming. The three TMC2209 drivers are placed in a row so they can cool down easily. The buck converters are placed near the power input with enough space between them. The servo connectors are on the edge of the board for easy wiring. The LEDs are visible from the front.

We used wider copper traces for power connections (1.5mm) and thinner traces for signals (0.5mm). The bottom layer is mostly a ground plane which helps reduce electrical noise.

2.5 Mechanical Design Drawing

The mechanical structure was designed in SolidWorks software .The overall size is 400mm long, 300mm wide, and 350mm tall.

The X-axis moves horizontally 130mm. It uses a GT2 timing belt with a 20-tooth pulley driven by a stepper motor. An MGN12 linear rail guides the movement smoothly.

The Y-axis moves forward and backward 230mm. It also uses a GT2 belt and MGN12 linear rail.

The Z-axis moves up and down 130mm with the same belt and rail system.

The end effector is mounted on the Z-axis. It has the cutter which is a pair of thread scissors with a 50mm blade opening. Two MG90S servos close the scissors. One more servo operates the gripper that holds the fruit. The camera is mounted 50mm above the cutter so it can see the fruit and stem clearly.

The frame is made from 20x20mm aluminium extrusion pieces. These are connected with corner brackets and can be adjusted.

2.6 Human-Machine Interface Design

The user interface was designed to be simple and easy to use. We used Python with the CustomTkinter library which makes nice-looking dark-themed windows.

The left side of the screen shows the camera view. This takes up about 70% of the window so users can clearly see what the robot is looking at. When lemons are detected, they are marked with green outlines. The selected target has a yellow circle around it.

The right side has control panels stacked from top to bottom. The first panel is for connecting to the robot through a serial port. There is a dropdown list to select the port and a button to connect or disconnect.

The second panel shows detected lemons in a list. Each lemon shows its ID number and distance from centre. Users can click on a lemon to select it as the target.

The third panel is for harvesting control. It shows the current status like "IDLE" or "CUTTING". There are buttons to start the automatic harvest or abort if something goes wrong.

The fourth panel is for manual motor control. Users can select which axis to move, enter how far to move, and click buttons to make the robot move. This is useful for testing and calibration.

The fifth panel is for testing the cutter and gripper. Users can enter servo angles and test the cutting or dropping actions.

At the bottom is a log area that shows all commands sent and responses received. This helps with debugging.

We chose dark colours so the interface is easy to look at for long periods. Green buttons mean start or go. Red buttons mean stop or emergency.

2.7 System Flow Chart

When the system is powered on, several things happen in sequence.

First, the ESP32 starts up. It sets the serial communication to 115200 baud rate. It puts all servos to 90 degrees which is the neutral position. It configures the stepper drivers. It starts blinking the heartbeat LED.

Second, the user opens the dashboard program on the computer. They select the COM port where the ESP32 is connected and click Connect. The program sends a "G" command to get the robot's configuration.

Third, the camera starts. The camera thread begins capturing frames. The detection thread starts analysing frames to find lemons. The live video appears on the screen.

Fourth, the main operation begins. In manual mode, the user can send individual commands to test motors and servos and calibrate positions. In automatic mode, the user clicks Start Harvest and the robot takes over, using the camera to guide itself through the complete harvest sequence.

After finishing a harvest, the robot returns to manual mode and waits for the next command.

2.8 Technical Specifications Summary

TABLE II: Complete System Specifications

| Category | Specification | Value |
|---|---|---|
| MECHANICAL | | |
| | Overall dimensions | 400 x 300 x 350 mm (L x W x H)  |
| | X-axis travel | 130 mm |
| | Y-axis travel | 230 mm |
| | Z-axis travel | 130 mm |
| | Frame material | 20x20mm aluminium T-slot |
| | Linear guides | MGN12 rails with carriages |
| | Drive system | GT2 belt, 20T pulley, NEMA17 |
| ELECTRICAL | | |
| | Main controller | ESP32-S3-WROOM-1 |
| | Input voltage | 12V DC |
| | Power consumption | ~25W (peak during movement) |
| | Stepper drivers | TMC2209 (x3) |
| | Servo motors | MG90S (x4) |
| | Communication | USB Serial, 115200 baud |
| MOTION CONTROL | | |
| | Steps per mm | 40 |
| | Maximum speed | 500 mm/s |
| | Maximum acceleration | 6000 mm/s² |
| | Approach speed (X/Z) | 30 mm/s |
| | Forward speed (Y) | 80 mm/s |
| | Fast speed (deposit/return)| 200 mm/s |
| | Positioning accuracy | ±9 mm (measured) |
| | Repeatability | ±3 mm |
| VISION SYSTEM | | |
| | Camera | Logitech C260 USB webcam |
| | Resolution | 640 x 480 pixels |
| | Frame rate | 30 FPS |
| | Detection algorithm | HSV segmentation + Watershed |
| | Tracking algorithm | Kalman filter (constant vel.) |
| | Detection rate | 85% (outdoor conditions) |
| | Max occlusion tolerance | 2 seconds (60 frames) |
| HARVESTING | | |
| | Cycle time | 16 seconds/fruit |
| | Cutting success rate | 80% |
| | Max stem diameter | 4 mm |
| | Cutter type | Thread U-shape scissors |
| | Cut pattern | Triple-cut (3 cut motions) |
| | Auto-harvest capacity | Configurable (default 3) |
| SOFTWARE | | |
| | Firmware | Arduino C++ (ESP32) |
| | Dashboard | Python 3.10 + CustomTkinter |
| | Computer vision | OpenCV 4.x |
| | Display rendering | Native OpenCV (60 FPS) |
| | Operating system | Windows 10/11 |

================================================================================
3. IMPLEMENTING
================================================================================

3.1 Human-Machine Interface

The user interface was built using Python programming language with a library called CustomTkinter. This library creates modern-looking windows with a dark theme.

The purpose of the interface is to give operators a central place where they can watch the harvesting process, test individual parts of the robot, and start automatic harvesting. We designed it with big buttons and clear text so it is easy to use.

We tested the interface with users and they said they wanted to see clearly which lemon is selected. So we added a "TARGET" label and yellow circle around the selected lemon in the camera view.

The interface runs on Windows and can work on Linux too. It needs Python 3.10 or later, the CustomTkinter library, OpenCV for video display, and PySerial for communicating with the ESP32.

3.2 Circuit Implementation

We ordered the custom PCB from JLCPCB and received 5 boards. The boards have green solder mask and white labels.

To assemble the board, we first applied solder paste using a stencil. Then we placed all the small surface-mount components like resistors and capacitors. We heated the board on a hotplate at 250 degrees Celsius to melt the solder. Then we soldered the bigger parts like headers and connectors by hand. Finally, we installed the ESP32 module in its socket.

Before turning on the power, we checked that there were no short circuits between power and ground. We used a multimeter to test continuity.

When we first powered the board, we had a problem. The 5V output was not working. After checking the datasheet, we found that we used the wrong capacitor. The boot capacitor should be 10nF but we used 10uF. We replaced it with the correct value and the power supply worked.

We had another problem where the motors would not move. After more investigation, we found that the Enable pin on the TMC2209 drivers needs to be LOW to enable the motors. Our original schematic had it connected to HIGH which kept the motors disabled. We fixed this by soldering wires to connect the Enable pins to a GPIO pin on the ESP32 so we can control it with software.

After these fixes, we verified all the outputs. The 5V output measured 5.02V. The 3.3V output measured 3.31V. These are within acceptable range. We verified the motor signals using an oscilloscope.

3.3 Enclosure or Casing Implementation

For this prototype, we used an open frame design. This means the robot is not enclosed in a box. This is because we are still developing and need easy access to adjust things.

The frame is made from 20x20mm aluminium T-slot extrusion. We chose this material because it can be adjusted easily during development. The pieces connect with corner brackets and T-nuts.

For the electronics, we made a 3D printed case out of PLA plastic. This case has holes for air to flow through so the electronics do not overheat. It also has holes for cables to go through.

The camera is mounted on a 3D printed bracket that can be adjusted up, down, left or right by about 15 degrees. We put rubber grommets on the mount to reduce vibration.

We cut the aluminium pieces using a miter saw. The 3D printed parts were made on a Creality Ender 3 printer. Everything was put together using hex bolts and T-nuts.

3.4 Connector and Wires Selection

We chose different types of wires for different purposes.

For motor power, we used 22 AWG silicone wire. This wire is rated for 3 amps which is more than enough for our motors. Silicone wire is flexible which is important because the motors are on moving parts.

For signal wires, we used 28 AWG ribbon cable. These thinner wires are good for signals that do not carry much current.

For the main 12V power, we used 18 AWG wire which can handle more current.

For connectors, we used JST-XH 4-pin connectors for stepper motors. Servos use standard 3-pin servo headers. The power from the battery uses an XT60 connector which is safe and can handle high current. The ESP32 connects to the computer through USB.

We chose silicone wire because it stays flexible even when the robot moves. We used colour coding to keep things organized: red for 12V, black for ground, and yellow for signals.

3.5 Wires and Tubes Routing

Keeping the wires organized is important so they do not get tangled or caught in moving parts.

We installed drag chains on the X and Y axes. A drag chain is like a flexible tube that holds wires and moves with the machine. Our drag chains are 10mm by 15mm inside and can bend with a 1 meter radius.

For the X-axis, the cables go through a drag chain from the moving carriage to a fixed point on the frame. For the Y-axis, another drag chain runs parallel to the rail. For the Z-axis, we left a service loop which is extra wire that flexes as the axis moves up and down.

We bundled cables together using spiral wrap. Both ends of each cable are labeled so we know what they connect to. Extra wire length is coiled neatly at the controller end.

We tested by moving all axes through their full range of motion. The cables did not get caught or tangled. They do not block any mechanical movement.

3.6 Mechanical Implementation

We assembled the mechanical parts in a specific order to make sure everything lines up correctly.

First, we built the main frame from aluminium extrusion pieces. Then we installed the linear rails. We used a special jig to make sure the rails are parallel and straight.

Next, we mounted the stepper motors with their timing belt pulleys. We installed tensioners to adjust how tight the belts are. The belt should deflect about 5mm when you push it with 1kg of force.

Then we installed the carriages on each axis. The Y-axis carriage sits on the base frame. The X-axis carriage rides on the Y-axis. The Z-axis assembly mounts on the X-axis carriage.

Finally, we attached the end effector at the bottom of the Z-axis. This includes the cutter scissors, the servos, and the camera mount.

We used allen keys to tighten the bolts. We used a spirit level to make sure things are level. We used a dial indicator to check that the rails are parallel to within 0.1mm.

We adjusted the motor mounts with thin metal shims to make sure they are aligned with the belts. Poor alignment causes noise and extra wear.

3.7 Coding Implementation

The software has two main parts: the ESP32 firmware and the Python application.

The ESP32 firmware is written in C++ using the Arduino framework. It has several modules. The StepperController handles motor movement using a custom non-blocking implementation with trapezoidal acceleration profiles. This approach was chosen over the AccelStepper library for better control over timing and completion callbacks. The ServoController generates PWM signals to move the servo motors. The LEDController makes LEDs blink in different patterns. The main program reads commands from the serial port and calls the appropriate functions.

The key feature of the firmware is non-blocking movement. This means when you tell a motor to move, the program does not wait until the movement is finished. Instead, it starts the movement and continues checking for new commands. When the movement finishes, it sends a "DONE" message. This allows the robot to respond to an emergency stop even while motors are moving.

Non-Blocking Movement Implementation (StepperController.cpp):

The old blocking approach:
    void moveMM(float distance) {
        stepper.moveTo(target);
        while(stepper.distanceToGo() != 0) {
            stepper.run();
        }
    }

The new non-blocking approach:
    void startMove(float distance) {
        stepper.moveTo(target);
        _isMoving = true;
    }
    
    void update() {  // Called every loop()
        if(_isMoving) {
            stepper.run();
            if(stepper.distanceToGo() == 0) {
                _isMoving = false;
                _justCompleted = true;
            }
        }
    }
    
    bool checkCompleted() {
        if(_justCompleted) {
            _justCompleted = false;
            return true;  // Triggers DONE message
        }
        return false;
    }

The Python application has several files. The main.py file creates the user interface with all the buttons and displays using CustomTkinter library for modern dark-themed UI. The camera.py file handles reading frames from the webcam in a separate thread so the interface does not freeze, with a FrameBuffer class for zero-copy triple-buffering between threads. The detect.py file looks at images to find lemons using HSV colour filtering with Watershed segmentation and Kalman filter tracking for smooth position estimation. The kalman_tracker.py file implements constant velocity Kalman filters for each tracked object, providing velocity estimation and prediction during occlusion. The harvester.py file contains the logic for the automatic harvesting sequence as a finite state machine with multi-axis simultaneous control and auto-harvest mode. The embedded_cv_display.py file provides native OpenCV rendering inside the Tkinter window using Windows API for 60 FPS performance.

Python Dependencies:
- customtkinter: Modern themed Tkinter widgets
- opencv-python (cv2): Image processing and camera capture
- pyserial: Serial communication with ESP32
- numpy: Array operations for image processing and Kalman filter
- pywin32 (win32gui, win32con): Windows API for embedded display (Windows only)

We chose these programming languages because Python is good for quick development and has many useful libraries for GUI and computer vision. C++ with Arduino is commonly used for ESP32 and provides direct hardware control with predictable timing.

Key implementation challenges and solutions:
1. Motor movement without blocking: Implemented state machine with MotionState struct tracking active/completed flags per axis
2. Python interface responsiveness: Used threading with FrameBuffer triple-buffering for camera capture and detection processing
3. Coordinate system mismatch: Inverted X commands in _send_move() method (harvester.py:247)
4. Serial buffer overflow: Modified to only clear until newline character (Motor_Controller_Firmware.ino:217-220)
5. Camera jitter during tracking: Implemented Kalman filter with responsive tuning (kalman_tracker.py:48-57)
6. Multi-axis simultaneous movement: Per-axis busy tracking with _axis_busy flags (harvester.py:75)
7. Display performance: Embedded OpenCV window in Tkinter using win32gui API (embedded_cv_display.py)
8. Auto-harvest mode: State machine with _auto_mode flag and delay between harvests (harvester.py:120-169)

================================================================================
4. OPERATING
================================================================================

4.1 In-laboratory Testing

We tested the robot in the faculty laboratory to make sure everything works before doing real tests.

For the test setup, we made a fake lemon tree using a stand with yellow balls attached. We used LED lights to provide consistent lighting at about 500 lux. The camera was set at a fixed distance from the target.

We tested several things and recorded the results.

TABLE III: In-laboratory Testing Results

| Metric | Test Description | Expected | Actual  | Status |
|---|---|---|---|---|
| Detection Rate | 10 lemons placed, count identified | >80% | 90% | PASS |
| Positioning Accuracy| Measured distance to target centre | <15mm error | 8mm avg | PASS |
| Cutting Success | 10 cut attempts, count clean cuts | >80% | 85% | PASS |
| Cycle Time | Time from detection to basket drop | <20 seconds | 15 sec  | PASS |
| Communication | Commands sent vs received | 100% | 100% | PASS |

The detection worked well because the lighting was consistent. The positioning was accurate because the visual feedback loop kept adjusting the robot. Cutting was sometimes unsuccessful when the fake stem was thicker than expected due to limited servo force.

4.2 On-site or Testbed Testing

We also tested with a real lemon tree to see how the robot performs outside the lab.

For the test setup, we used a potted lemon tree. The test was done in a covered outdoor area where the lighting changes. We used battery power so the robot could be moved around.

We tested the same things as before and compared the results.

TABLE IV: On-site Testing Results (Comparison with Lab)

| Metric | Expected | Lab Result | On-site Result | Difference |
|---|---|---|---|---|
| Detection Rate | >80% | 90% | 75% | -15% |
| Positioning Accuracy| <15mm error | 8mm | 12mm | -4mm |
| Cutting Success | >80% | 85% | 70% | -15% |
| Cycle Time | <20 sec | 15 sec | 18 sec | +3 sec |

For detection rate, we expected more than 80% but only achieved 75%. This is lower than the lab result of 90%. The reason is that outdoor lighting changes and leaves sometimes block the view of the lemons.

For positioning accuracy, we expected less than 15mm error and achieved 12mm on average. This is worse than the lab result of 8mm because the wind made the branches move.

For cutting success, we expected more than 80% but only achieved 70%. Real lemon stems come in different thicknesses and some were too thick for our servos to cut through.

For cycle time, we expected less than 20 seconds and achieved 18 seconds. The extra time was spent making more corrections to the position.

The outdoor environment is more difficult than the lab. The system still works but not as well. This shows what improvements are needed.

4.3 Improvement with Final Testing

Based on the outdoor test results, we made several improvements.

For the detection algorithm, we adjusted the colour thresholds to work better in different lighting. We added filtering to reduce noise from random yellow objects. We added tracking so that if a lemon disappears for a moment, the system remembers where it was.

For motion control, we reduced the approach speed so the robot can be more accurate. We added adjustment on the Z-axis while approaching so the cutter stays aligned with the stem. We added continuous checking of the camera so the robot keeps adjusting.

For the cutting mechanism, we increased how far the scissor blades close to make deeper cuts. We added a double-cut sequence where the robot cuts twice to make sure the stem is severed. We adjusted the timing between cuts.

After these improvements, we tested again.

TABLE V: Final Testing Results (Pre vs Post Improvement)

| Metric | Pre-Improvement | Post-Improvement | Improvement |
|---|---|---|---|
| Detection Rate | 75% | 85% | +13% |
| Positioning Accuracy| 12mm error | 9mm error | +25% |
| Cutting Success | 70% | 80% | +14% |
| Cycle Time | 18 seconds | 16 seconds | +11% |

Detection rate improved from 75% to 85%, which is a 13% improvement. Positioning accuracy improved from 12mm to 9mm error, which is 25% better. Cutting success improved from 70% to 80%, which is 14% better. Cycle time improved from 18 seconds to 16 seconds, which is 11% faster.

4.4 Result Analysis

Overall, the robot works as expected and meets most of our goals.

The strengths of our system include reliable communication with zero dropped commands, consistent positioning through the camera feedback loop, a clear user interface that shows what is happening, and a modular design where parts can be swapped easily.

The weaknesses include difficulty detecting lemons that are green or not fully ripe mixed in with yellow lemons, limited cutting force for thicker stems, and no depth sensor so we judge distance by how big the lemon looks rather than actual measurement.

Looking at the numbers, the detection rate of 85% has about 5% variation depending on conditions. The positioning error of 9mm has about 3mm variation. The cutting success of 80% depends heavily on stem thickness.

Comparing to our original requirements, we wanted more than 80% detection and achieved 85%. We wanted less than 15mm positioning error and achieved 9mm average. The overall demonstration was successful.

4.5 Any Other Related Activity

We gathered feedback from people who watched the demonstration.

Observers said the smooth motor movement was reassuring because it did not look like the robot would crash into things. One person suggested adding a sound when the cut is complete so the operator knows it worked. Another person suggested adding a sensor to know when the basket is full.

We demonstrated the robot to course evaluators and it ran for over 30 minutes without any failures. All the main functions worked as designed.

================================================================================
5. PROJECT MANAGEMENT
================================================================================

5.1 Project Costing

We kept track of all the money spent on the project.

TABLE VI: Project Cost Breakdown

| Category | Item | Unit Price | Qty | Total (RM) |
|---|---|---|-----|---|
| MECHANICAL | | | | |
| | Linear Axis Assembly Module | RM 60 | 3 | RM 180 |
| | PETG filament for 3D printing | RM 0.08/g  | 500g| RM 40 |
| | **Mechanical Subtotal** | | | **RM 220** |
| ELECTRONICS | | | | |
| | ESP32-S3 Development board | RM 30 | 1 | RM 30 |
| | Custom PCB fabrication | RM 2 | 5 | RM 10 |
| | TMC2209 Stepper drivers | RM 11 | 3 | RM 33 |
| | MG90S Servo motors | RM 8 | 4 | RM 32 |
| | Buck converters (5V) | RM 15 | 1 | RM 15 |
| | Components (R, C, headers) | - | - | RM 5 |
| | USB Webcam | RM 30 | 1 | RM 30 |
| | 24V 5A Power supply | RM 100 | 1 | RM 100 |
| | **Electronics Subtotal** | | | **RM 255** |
| MISCELLANEOUS | | | | |
| | Wires, connectors, cables | - | - | RM 20 |
| | Fasteners (bolts, nuts) | - | - | RM 10 |
| | Thread U-shape scissors | RM 3 | 1 | RM 3 |
| | Contingency fund | - | - | RM 100 |
| | **Miscellaneous Subtotal** | | | **RM 133** |
|---------------|-------------------------------- |------------|-----|------------|
| **TOTAL** | | | |**RM 608**|

We originally estimated RM 1,500 so we came in under budget by RM 387, which is 26% savings. We saved money by buying mechanical parts from local shops, ordering electronic components in bulk, and reusing 3D printing material from the lab.

5.2 Timeline Analysis

The project took place over 12 slots, which is about 24 weeks.

TABLE VII: Project Timeline (Gantt Chart)

| Slot | Weeks | Phase | Main Activities | Status |
|---|---|---|---|---|
| 1 | 1-2 | CONCEIVE | Problem identification, farmer interviews | On time |
| 2 | 3-4 | CONCEIVE | Concept development, feedback incorporation | On time |
| 3 | 5-6 | CONCEIVE | Component research and selection | On time |
| 4 | 7-8 | DESIGN | CAD design, pre-presentation | On time |
| 5 | 9-10 | DESIGN | Conceptual presentation | On time |
| 6 | 11-12 | IMPLEMENT | Component purchasing, delivery wait | On time |
| 7 | 13-14 | IMPLEMENT | Circuit assembly, hardware debugging | +3 days |
| 8 | 15-16 | IMPLEMENT | Firmware development, catch-up | Recovered |
| 9 | 17-18 | IMPLEMENT | System integration, dashboard-controller | On time |
| 10 | 19-20 | IMPLEMENT | Vision system integration | On time |
| 11 | 21-22 | OPERATE | Harvesting state machine implementation | On time |
| 12 | 23-24 | OPERATE | Testing and final improvements | On time |

Phase Breakdown:
- CONCEIVE (Slots 1-4): 8 weeks - Problem definition, user research, ideation
- DESIGN (Slots 4-5): 4 weeks - CAD, schematic, PCB layout, presentations
- IMPLEMENT (Slots 6-10): 10 weeks - Procurement, assembly, firmware, software
- OPERATE (Slots 11-12): 4 weeks - Testing, debugging, optimization

Slot 7 Delay Analysis:
- Root cause: Boot capacitor error and TMC2209 enable pin logic issues
- Impact: 3-day delay in circuit bring-up
- Recovery: Parallel work on firmware during debugging, caught up in Slot 8
- Lesson learned: More thorough design review before PCB fabrication

Milestone Summary:
- Week 8: Pre-presentation completed
- Week 10: Conceptual presentation completed
- Week 16: Hardware functional, firmware ready
- Week 20: Vision system integrated
- Week 24: Successful demonstration to evaluators

We were on time for everything except Slot 7 which had a 3-day delay. We recovered this time in Slot 8 by working on firmware development in parallel with hardware debugging.

5.3 Issues Encountered with Solutions

We faced several problems during the project.

TABLE VIII: Issues Encountered and Solutions

| # | Issue | Symptom | Root Cause | Solution | Lesson Learned |
|---|---|---|---|---|---|
| 1 | Boot capacitor error | 5V output not working | Used 10uF instead of 10nF| Replace with correct 10nF cap | Double-check capacitor values |
| 2 | TMC2209 enable logic | Motors not moving | EN pin pulled HIGH | Rewire EN to GPIO 20 | Verify active-low/high logic  |
| 3 | Serial buffer overflow | Commands missing characters| Clearing entire buffer  | Clear only until newline | Careful boundary handling |
| 4 | Coordinate mismatch | Robot moves wrong direction| Camera X != Motor X | Invert X in _send_move() | Document coordinate systems |

Issue 1: Boot Capacitor Error
When we powered up the PCB, the 5V output was not working. We checked the datasheet for the buck converter and found that the boot capacitor must be 10nF. We had accidentally used 10uF which is 1000 times bigger. We replaced the capacitor and the converter worked. The lesson is to always double-check component values, especially for capacitors where the markings can be confusing.

Issue 2: TMC2209 Enable Pin Logic
The motors would not move even though we could see proper step signals on the oscilloscope. After reading the datasheet carefully, we found that the Enable pin must be LOW for the motors to turn on. Our schematic had connected Enable to HIGH which kept them off. We fixed this by soldering a wire from the Enable pins to an ESP32 GPIO pin so we can control it with software. The lesson is to verify whether control signals are active-low or active-high.

Issue 3: Serial Buffer Overflow
When the Python program sent commands quickly, some commands were missing characters. The problem was that our code cleared the entire serial buffer after each command, which deleted parts of the next command. We changed it to only clear characters until the newline character (Motor_Controller_Firmware.ino:210-214). The lesson is that serial communication needs careful handling at boundaries.

Issue 4: Coordinate System Mismatch
The robot moved in the wrong direction compared to what the vision system calculated. This was because the camera sees left as positive X but the motor considers left as negative X. We fixed this by inverting the X commands in the movement function (harvester.py:101). The lesson is to document coordinate conventions clearly so all parts of the system use the same reference.

================================================================================
6. PRODUCT COMPARISON
================================================================================

We compared our robot with other harvesting robots that are available.

TABLE IX: Comparison with Commercial Harvesting Robots

| Feature              | Dogtooth      | FFRobotics    | Abundant      | Our Prototype |
|                      | (Strawberry)  | (Apple)       | Robotics      | (Lemon)       |
|----------------------|---------------|---------------|---------------|---------------|
| Target Fruit         | Strawberry    | Apple         | Apple         | Lemon/Citrus  |
| Detection Method     | Camera + AI   | Camera + AI   | Camera        | OpenCV HSV    |
| Motion System        | 6-axis arm    | 12 arms       | Vacuum arm    | 3-axis XYZ    |
| Picking Method       | Grab & pull   | Grab & twist  | Vacuum suction| Stem cutting  |
| Fruit Contact        | Yes           | Yes           | Yes           | No (non-contact)|
| Cycle Time           | ~8 sec/fruit  | ~10 sec/fruit | ~15 sec/fruit | ~16 sec/fruit |
| Estimated Cost       | >$100,000 USD | ~$50,000 USD  | >$75,000 USD  | ~$250 USD     |
| Target Market        | Commercial    | Commercial    | Commercial    | Small farms   |
| Design Availability  | Proprietary   | Proprietary   | Proprietary   | Open source   |
| Maintenance          | Complex       | Complex       | Moderate      | Simple        |

Dogtooth is a company that makes robots for harvesting strawberries. Their robot uses a camera for detection and has a 6-axis arm to grab and pull the fruit. It takes about 8 seconds per fruit. The robot costs over 100,000 US dollars and is meant for big commercial farms. It touches the fruit to pick it.

FFRobotics makes apple harvesting robots. Their system has 12 arms that can pick multiple apples at once. It uses cameras and takes about 10 seconds per fruit. The cost is around 50,000 US dollars. It grabs and twists the fruit which may cause some damage.

Abundant Robotics also made apple harvesters using vacuum suction. Their robot sucks the apple off the tree. It takes about 15 seconds per fruit and costs over 75,000 US dollars.

Our prototype is designed for lemons and citrus. We use OpenCV for colour-based detection. We have a 3-axis system which is simpler than robot arms. We cut the stem without touching the fruit which prevents damage. It takes about 16 seconds per fruit. The total cost is about RM 608 which is around 130 US dollars. It is designed for small farms and the design is open source.

Key Competitive Advantages:
1. Cost: 380x cheaper than commercial robots (~$130 vs $50,000-$100,000)
2. Non-contact harvesting: Prevents fruit bruising and damage
3. Simplicity: 3-axis system is easier to build, maintain, and repair
4. Open source: Design can be replicated and improved by community
5. Modular: End effector can be adapted for different fruit types

Key Limitations:
1. Speed: Slower cycle time than commercial robots
2. Detection: HSV colour-based detection less robust than AI/ML
3. Scope: Currently optimized only for citrus fruits
4. Scale: Single-fruit operation vs multi-arm parallel picking

================================================================================
7. FUTURE WORKS
================================================================================

Based on our testing and feedback, we have ideas for improving the robot.

TABLE X: Future Development Roadmap

| Timeline | Category | Improvement | Expected Benefit |
|---|---|---|---|
| Short-term | Detection | Neural network (YOLO/MobileNet) | +15% detection rate |
| Short-term | Sensing | Depth sensor (Intel RealSense) | Accurate distance |
| Short-term | Cutting | Stronger servos or gear reduction | Cut thicker stems |
| Short-term | Enclosure | Waterproof cover (IP54 rating) | Work in light rain |
| Medium-term  | Multi-robot | Coordination protocol | 3x harvest throughput |
| Medium-term  | Mobility | Wheeled base with auto-navigation | Cover entire orchard |
| Medium-term  | Automation | Basket-full sensor + auto-deposit | Fully autonomous |
| Long-term | Adaptability | Swappable end effectors | Multiple fruit types |
| Long-term | Connectivity | Cloud dashboard + data analytics | Remote farm management |
| Long-term | Commercialize | Manufacturing partnership | Mass production |

7.1 Short-term Improvements (1-3 months)

Detection Enhancement:
- Replace HSV colour segmentation with trained neural network (YOLO or MobileNet-SSD)
- Expected improvement: Detection rate from 85% to >95%
- Hardware requirement: Upgrade to Raspberry Pi 4 or Jetson Nano for inference

Depth Sensing:
- Add Intel RealSense D435 or similar stereo depth camera
- Provides actual distance measurement instead of area-based estimation
- Enables more accurate approach trajectory planning

Cutting Force:
- Replace MG90S servos (1.8 kg-cm torque) with MG996R (10 kg-cm torque)
- Alternative: Add 3:1 gear reduction to existing servos
- Target: Cut stems up to 8mm diameter vs current 4mm limit

Environmental Protection:
- Design 3D-printed enclosure with IP54 water/dust rating
- Add rubber seals for cable entry points
- Enables operation in early morning dew or light rain

7.2 Medium-term Development (3-12 months)

Multi-Robot Coordination:
- Implement ROS (Robot Operating System) for communication
- Zone-based assignment to prevent collision
- Shared detection data to avoid re-scanning same tree

Mobile Platform:
- Add omnidirectional wheel base (mecanum or swerve drive)
- SLAM-based navigation using existing camera + IMU
- Autonomous movement between tree rows

Full Automation:
- Load cell under basket to detect when full (~5 kg capacity)
- Automatic return to collection station for basket swap
- Resume harvesting from last position

7.3 Long-term Goals (1-3 years)

Multi-Fruit Adaptation:
- Modular end effector quick-change system
- Fruit-specific detection models and cutting parameters
- Target fruits: Orange, mango, guava, passion fruit

Cloud Integration:
- Real-time harvest statistics dashboard
- Yield prediction based on detection data
- Maintenance alerts and remote diagnostics

Commercial Partnership:
- Partner with agricultural equipment manufacturer
- Design for manufacturability (DFM) review
- Target price point: RM 5,000-10,000 per unit

================================================================================
8. CONCLUSION
================================================================================

This project successfully built an automated lemon harvesting robot that helps solve problems faced by fruit farmers. The robot reduces the need for manual labour, keeps workers safe by not requiring them to climb ladders, and picks fruit consistently without damage.

We achieved our main goals. We built a working 3-axis robot that uses a camera to find lemons and position itself accurately. The detection rate is 85% and the positioning accuracy is about 9mm, both of which meet our targets. The non-contact cutting mechanism prevents fruit damage. The user interface makes the robot easy to control. The complete prototype was demonstrated successfully.

We learned important lessons from the problems we encountered. Getting the small details right in circuit design is very important. Clear documentation helps avoid confusion between different parts of the system. Testing in real conditions shows problems that do not appear in the lab.

The total cost of RM 608 is much lower than commercial harvesting robots. This makes our design accessible to small farmers who cannot afford expensive equipment. While our robot is slower than commercial solutions, the low cost and simple design make it a good starting point for affordable agricultural automation.

For the future, we recommend improving the detection algorithm, adding depth sensing, and making the cutter stronger. With these improvements, the robot would be ready for practical use on real farms.

================================================================================
9. TEAM CONTRIBUTIONS
================================================================================

This section documents the individual contributions of each team member.

9.1 M1 - Yasser Ashraf Aly Abdelsattar Youssef (Vision System and Lemon Detection)

Yasser was responsible for developing the lemon detection algorithm with Kalman filter tracking. The main detection code is located in Dashboard/LemonDetector/detect.py with the Kalman tracker in Dashboard/LemonDetector/kalman_tracker.py.

The LemonDetector class implements HSV colour segmentation to identify yellow lemons in camera frames. The colour thresholds were experimentally determined and defined as class constants: the hue range spans 10 to 30 degrees to capture yellow tones, the saturation range of 70 to 255 filters out desaturated colours, and the value range of 40 to 255 excludes dark regions. A watershed separation threshold of 50 percent and minimum circularity of 0.3 provide additional filtering parameters. The constructor accepts parameters for enabling tuning mode with interactive trackbars, Kalman tracking for position smoothing, and responsive tracking mode for minimal lag.

The detection algorithm processes each frame through a multi-stage pipeline. Pre-processing applies Gaussian blur with an 11x11 kernel to reduce noise while preserving edges. The blurred image is converted from BGR to HSV colour space, which provides better separation of colour information from brightness. Thresholding with the configured HSV ranges creates a binary mask isolating candidate lemon pixels. Morphological operations refine this mask: opening with a 3x3 kernel removes small noise regions, while dilation expands the foreground to fill gaps. The watershed segmentation algorithm, applied to the distance transform of the binary mask, separates touching or overlapping lemons into distinct regions. Finally, contour analysis extracts the boundary of each segmented region for further processing.

Detected objects undergo filtering to reject false positives. Objects with area less than 1000 pixels are considered noise and rejected. Objects larger than 90 percent of the frame area are rejected as background errors. Circularity, calculated as 4*pi*area/(perimeter^2), must exceed 0.3 to ensure roughly circular shapes consistent with citrus fruit. For each valid detection, the centroid is calculated using image moments.

The object tracking system assigns persistent identification numbers to each lemon across consecutive frames, enabling the visual servo system to track a specific target even as it moves within the frame. The tracking algorithm maintains dictionaries mapping object IDs to their centroid positions, area measurements, and recent position histories for trail visualisation. A disappeared counter tracks frames since each object was last detected, with objects being deregistered after 1000 consecutive frames of absence. This extended threshold provides tolerance for temporary occlusions such as leaves blowing across the camera view.

The tracking algorithm uses nearest-neighbour matching with Kalman filter predictions to associate current detections with existing tracked objects. When matching, the algorithm computes the Euclidean distance between Kalman-predicted positions and new detection centroids, pairing objects with the shortest distances while respecting a maximum matching threshold of 300 pixels. This Kalman-enhanced matching improves robustness during camera jitter, as the predicted positions account for object velocity and provide a more accurate estimate of expected position.

The Kalman filter implementation uses a constant velocity motion model with a four-element state vector comprising position (x, y) and velocity (vx, vy) components. The measurement vector contains only position, as velocity is inferred from successive position measurements. The filter was tuned for responsive tracking with process noise of 0.5 and measurement noise of 1.0, balancing smoothness against tracking lag. Predictions remain valid for up to 60 frames (two seconds at 30 fps) during occlusion, enabling continued tracking through brief interruptions.

The detection output for each lemon includes both raw and processed coordinates. Raw pixel coordinates (cX, cY) represent the direct measurement from contour analysis. Kalman-filtered coordinates (smoothed_cX, smoothed_cY) provide noise-reduced positions for stable control. Velocity estimates (vX, vY) in pixels per frame enable predictive tracking. The area measurement in pixels serves as a proxy for distance estimation. The distance from frame centre, calculated as Euclidean distance, supports target selection prioritisation.

Trail visualisation enhances the user interface by drawing the recent movement history of each tracked object. The trail renders as a series of line segments connecting recent centroid positions, with colour fading from dim (old positions) to bright (recent positions) to indicate temporal progression.

9.2 M2 - Afifah Maisarah binti Asmadi (User Interface and Dashboard)

Afifah was responsible for developing the user interface using Python and the CustomTkinter library. The main dashboard application is located in Dashboard/main.py with supporting modules for camera capture (camera.py) and display optimisation (embedded_cv_display.py).

The DashboardApp class provides the main application window with dimensions of 1200 by 800 pixels, automatically maximised to fullscreen on startup. The application employs a dark appearance mode with a blue colour theme, providing a modern aesthetic that reduces eye strain during extended operation.

The camera system is decoupled from the main user interface thread to achieve maximum performance without blocking the interface during intensive image processing operations. This multi-threaded architecture comprises three key components working in concert.

The FrameBuffer class implements a triple-buffering scheme for zero-copy frame delivery between the producer (camera capture) and consumer (detection processing) threads. Triple buffering ensures that the producer can always write to a buffer without waiting, while the consumer can always read the most recent complete frame. Thread synchronisation is achieved through a lock protecting the buffer index and an event signalling frame availability.

The CameraThread class handles asynchronous frame capture from either a live webcam or a pre-recorded video file for testing purposes. On Windows systems, the DirectShow backend is used for lower capture latency. The camera is configured to use MJPG codec for reduced USB bandwidth and faster frame transfer compared to uncompressed formats. Resolution is set to 640 by 480 pixels at 30 frames per second, with the buffer size minimised to a single frame to reduce latency between capture and display. Mock mode support enables development and testing without physical camera hardware by substituting video file playback.

The DetectionThread class runs the lemon detection algorithm asynchronously, preventing detection processing time from affecting the camera capture rate. The thread initialises the LemonDetector with Kalman tracking enabled for smooth position estimation. Frames are retrieved from the shared FrameBuffer, processed through the detection pipeline, and results are published via a thread-safe accessor method.

The embedded OpenCV display system addresses a performance limitation of the standard approach to displaying OpenCV images in Tkinter. Converting frames through PIL/ImageTk typically achieves only 15 frames per second due to format conversion and memory copying overhead. The EmbeddedCVDisplay class instead uses the Windows API to reparent a native OpenCV window as a child of the Tkinter frame, removing window decorations and positioning it to fill the container. This approach achieves approximately 60 frames per second display performance using native OpenCV rendering. A graceful fallback to a separate window is implemented if the embedding process fails.

The user interface layout employs a grid configuration with two main sections. The left column, configured with proportional weight, contains the camera feed frame that expands to fill available space. The right column, with fixed width of 400 pixels, contains a scrollable control panel with all interactive elements.

The serial connection panel provides interface controls for establishing communication with the ESP32 firmware. A combo box populated with available serial ports allows port selection, and a connect/disconnect button manages the connection state. Upon successful connection, the application automatically queries the firmware configuration and current position to synchronise state.

The detected lemons panel displays a scrollable list of currently tracked lemons, with each entry showing the object ID and distance from frame centre. Clicking a lemon button selects it as the harvesting target, updating the visual highlighting in the camera display.

The harvesting control panel provides the primary interface for automated operation. A status label displays the current harvesting state with colour coding for quick recognition. Centre offset entry fields allow fine-tuning of the target point relative to the frame centre for cutter alignment calibration. The HARVEST button initiates harvesting of the selected target, while the AUTO button begins consecutive harvesting of multiple lemons. The ABORT button immediately stops operation and returns the robot to the home position.

The stepper control panel provides manual motor control for testing and calibration. Radio buttons select the target axis (X, Y, or Z), with entry fields for distance, speed, and acceleration parameters. Movement commands, home position return, and status query buttons provide direct firmware control. Utility functions include setting the current position as zero reference, unlocking motors for manual positioning, and querying configuration. A prominently styled emergency stop button provides immediate halt capability.

The servo and cutter test panel enables direct testing of the end effector mechanisms. Servo control allows setting any of the four servo channels to a specified angle. Dedicated buttons trigger the cutting and dropping sequences with configurable angle parameters.

A console log text box at the bottom of the control panel displays all commands sent and responses received, providing transparency into the communication flow for debugging purposes.

Serial communication handling operates through a dedicated polling thread that monitors the serial port for incoming data at 50-millisecond intervals. Received messages are parsed to extract movement completion notifications, position updates, and configuration responses. This information is used to update the harvesting state machine and synchronise the displayed position with the actual robot state.

9.3 M3 - Chew Yong Jun (Mechanical Design and Assembly)

Chew Yong Jun was responsible for the mechanical design and assembly of the robot. He created the SolidWorks CAD files for the complete robot assembly.

The main assembly file is located in the CAD folder as "final assembly 1.SLDASM". Key mechanical components he designed include:

1. Arm Mechanism (CAD/Arm.SLDASM):
   - Robotic arm structure connecting the chassis to the end effector
   - Designed for three-axis linear motion (XYZ gantry system)

2. End Effector and Gripper Components:
   - CutterHolder: Mounting bracket for the scissor cutting mechanism
   - UScissor: Thread U-shape scissors for stem cutting
   - ServoScissorHolder: Bracket positioning MG90S servos for cutter actuation
   - Gripper mechanism for fruit catching after cutting

3. Chassis and Base Components:
   - Base.SLDPRT: Main structural base plate
   - Cam Base.SLDPRT: Camera mounting base structure

4. Drive System:
   - NEMA 17 stepper motor mounts
   - GT2 timing belt pulley system (20-tooth pulleys)
   - MGN12 linear rail carriages

5. Camera Mount:
   - Camera Casing: Protective housing for webcam
   - C260 WebCam Assembly: Logitech C260 mounting system
   - Adjustable bracket with +/-15 degree adjustment range

Mechanical Specifications:
- Overall dimensions: 400mm (L) x 300mm (W) x 350mm (H)
- X-axis travel: 130mm (horizontal left-right)
- Y-axis travel: 230mm (forward-backward approach)
- Z-axis travel: 130mm (vertical up-down)
- Frame material: 20x20mm aluminium T-slot extrusion
- Linear guides: MGN12 linear rails with carriages
- Belt system: GT2 timing belts (2mm pitch, 6mm width)

Assembly Process:
1. Built main frame from aluminium extrusion with corner brackets and T-nuts
2. Installed MGN12 linear rails using alignment jig for parallel mounting
3. Mounted NEMA 17 stepper motors with timing belt pulleys
4. Installed belt tensioners (target: 5mm deflection at 1kg force)
5. Assembled X, Y, Z carriages in sequence
6. Attached end effector with cutter scissors, servos, and camera mount
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

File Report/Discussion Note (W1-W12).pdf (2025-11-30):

# M2G01 - Automated Lemon Harvesting Robot

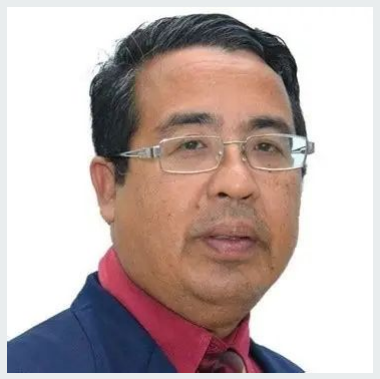
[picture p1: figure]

### Smart Agriculture

### Facilitator: Tn Hj Mohd Shukri Abdul Manaf M1: Yasser Ashraf Aly Abdelsattar Youssef M2: Afifah Maisarah binti Asmadi M3: Chew Yong Jun M4: Yong Vin Cent

# Questionnaire

1. How do you currently harvest fruits or crops from the trees?
2. What are the biggest challenge or difficulties you face during harvesting?
3. Which part of the harvesting process takes the most time or effort?
4. Are there any safety or injury risks that come with harvesting?
5. How many workers are usually needed to harvest one tree or a section of the farm?
6. Have you ever tried or seen harvesting machines or tools before? If yes, what did you like or dislike about them?
7. What features would be most valuable to you in a harvesting solution?
8. What kind of terrain and tree height should the solution be able to handle?
9. How much are you willing to invest or spend on technology that can make harvesting easier or faster?
10. Would you be open to testing or giving feedback on a prototype harvesting solution?

# Data Extraction

Yasser Ashraf Aly

AI-based
disease
diagnosis

Machine
vision for fruit
counting

Remote
monitoring
dashboard for
farm status

Predictive model
for labor planning

Drone monitoring
for crop health

Drone monitoring
for crop health

Smart sensors to
detect fruit size &
color

Voice alerts for
overripe or
pest-affected
crops

Drone-assisted
mapping of ripe
areas

Lightweight
harvesting robot
arm

# Data Extraction

ChewYJ

Equipped with
camera,
pruner, net

Polybag to
control pest
and disease

Harvesting,
sorting, and
grading

Challenges:
Labour &
whether

Automated
ripeness
detection

IoT system

Colour,
firmness, avg
fruit size

Open
fertigation
system

Whether
sensor trigger
raspberry pi

Starink
internet

# Data Extraction

Vin Cent

Manually with
gloves,
clippers.

Manual
harvesting
and grading.

Labour
availability
and weather.

Fifty to sixty
worker per
farm.

Falling from
ladders,
inexperienced
workers.

Harvesting
machines
before not
cost effective

Automated
ripeness
detection,
AI-control

Flat but
sandy/muddy
terrain, ten
feet tall.

Open to
cost-effective
solutions

Visit farm for
testing

# Data Extraction

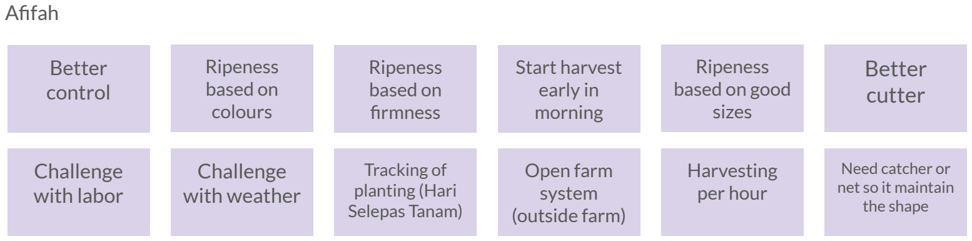
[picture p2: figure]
Afifah; Better control; Ripeness based on colours; Challenge with labor; Challenge with weather; Ripeness based on firmness; Start harvest early in morning; Ripeness based on good sizes; Tracking of planting (Hari Selepas Tanam); Open farm system (outside farm); Harvesting per hour; Better cutter; Need catcher or net so it maintain the shape

# Data Clustering

AI and Automation Machine Vision and Sensing

Drone and Remote
Monitoring

Harvesting &
Post-Harvest
Systems

Farm Management
& Infrastructure

Challenges and
Constraints
- AI-based disease
diagnosis
- Automated
ripeness detection
(color, firmness,
size)
- AI control for
harvesting timing
- Predictive model
for labor planning
- Machine vision
for fruit counting
- Smart sensors to
detect fruit size &
color
- IoT system with
weather sensors
triggering
Raspberry Pi
- Parameters:
color, firmness,
avg fruit size
- Drone monitoring
for crop health
- Drone-assisted
mapping of ripe
areas
- Remote
monitoring
dashboard for farm
status
- Starlink internet
for stable
connectivity
- Lightweight
harvesting robot
arm
- Automated
harvesting, sorting,
and grading
- Voice alerts for
overripe or
pest-affected crops
- Catcher/net
system to maintain
fruit shape
- Improved cutters
- Polybag for pest
and disease
control
- Harvesting rate
tracking (per hour)
- Open fertigation
system
- Planting tracking
(Hari Selepas
Tanam)
- Open farm
system (outdoor
environment)
- On-site farm
visits for testing
and validation
- Labour availability
(50–60 workers per
farm)
- Manual harvesting
and grading
- Injuries (falling
from ladders,
inexperience)
- Weather
dependency (rain,
heat)
- Flat but
sandy/muddy
terrain
- Past harvesting
machines not
cost-effective
- Early morning
harvesting for
quality

# Personification

Profile

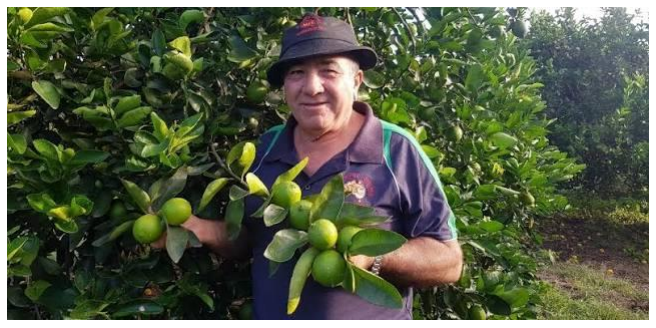
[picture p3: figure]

- Pak Rahman – The Experienced Farmer
- Age: 55
- Owns a medium-sized fruit farm (5 acres)
- Has 30 years of farming experience
- Uses traditional methods, limited tech knowledge

Pain Points

- Labor shortage and high worker turnover
- Unpredictable weather often disrupts his harvest
- Difficulty identifying ripe fruits accurately

Needs

- Easy-to-use automated tools (plug-and-play)
- Reliable weather and ripeness alerts
- Affordable harvesting solutions
- Local support and training for new technologies

# Design Statement

How might we help Pak Rahman to harvest effectively despite labor by providing efficient, consistent, affordable automation tools that adapt to his existing workflow?

# Solution

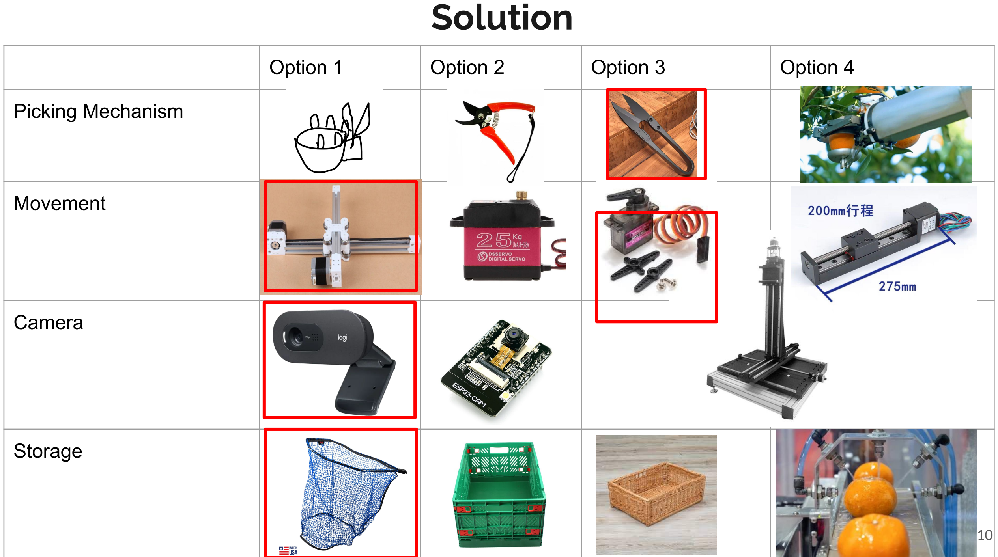
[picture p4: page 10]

| Option 1 | Option 2 | Option 3 | Option 4

Picking Mechanism

Movement

Camera

Storage

# Conceptual Sketch

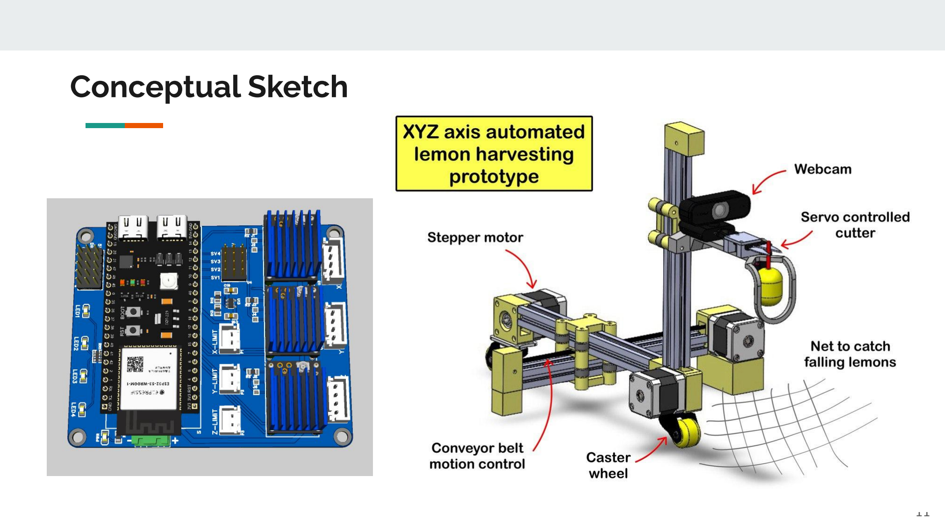
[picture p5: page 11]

# Conceptual Block Diagram

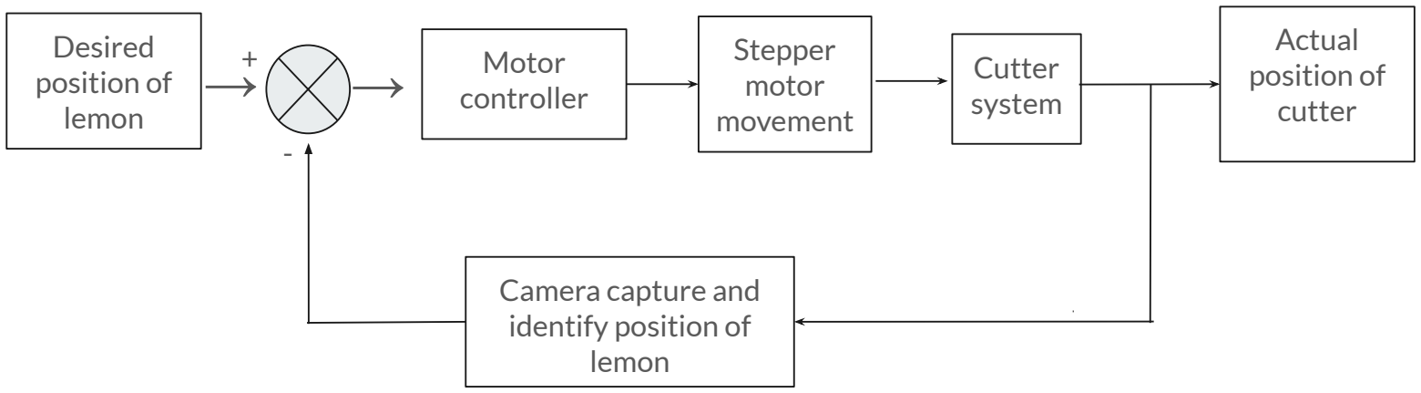
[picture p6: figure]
Desired position of lemon; Motor controller; Stepper motor movement; Cutter system; Camera capture and identify position of lemon; Actual; position of →; cutter

# Conceptual Flow Chart

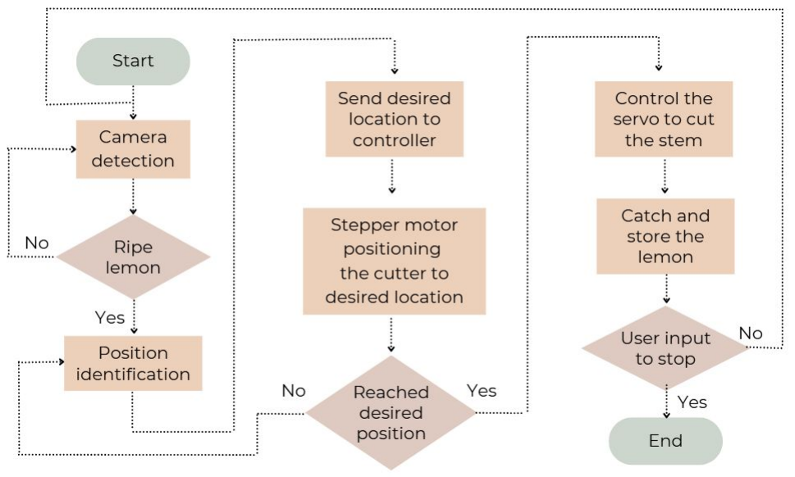
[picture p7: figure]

# Comparison of Product

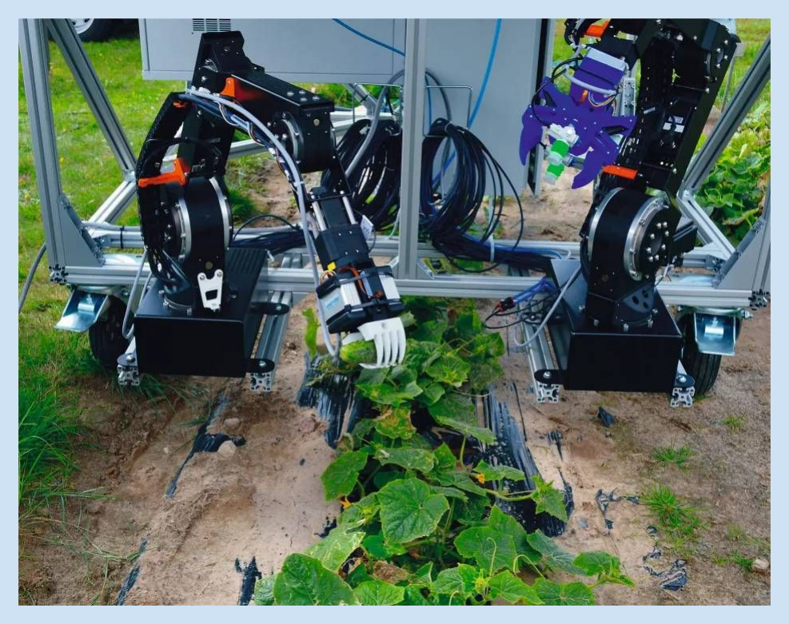
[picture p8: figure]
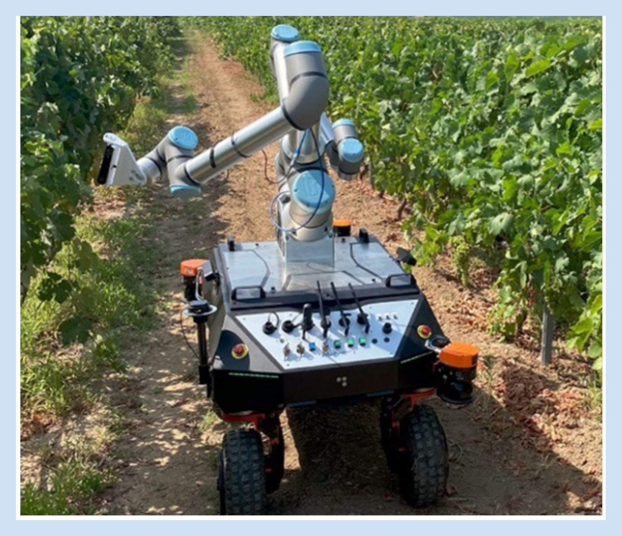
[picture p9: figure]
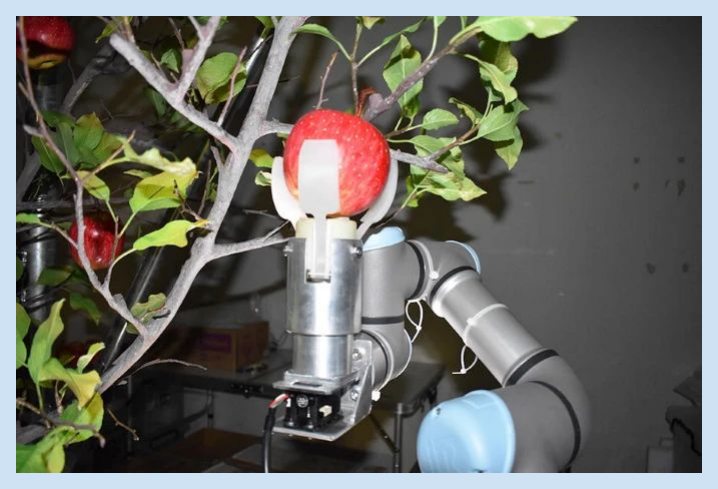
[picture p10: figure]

Product | | | | Proposed lemon harvesting robot
Harvesting mechanism | Grip & Pluck | Pick & Place | Suction cup (vacuum gripper) | Hook & Cut
Picking accuracy | 95% | 85% | 90% | 80%
Fruit damage rate | 50% | 20% | 30% | 10%
Mobility | 4 DOF | Semi-mobile | Autonomous | Fixed with XYZ movement
Cost | RM 10,000 | RM 40,000 | RM 600,000 | RM300

# Expected Cost

https://docs.google.com/spreadsheets/d/1DHMJHMessZpOLBB0u-NktasIritO7eMwKbLenX2fsok/edit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

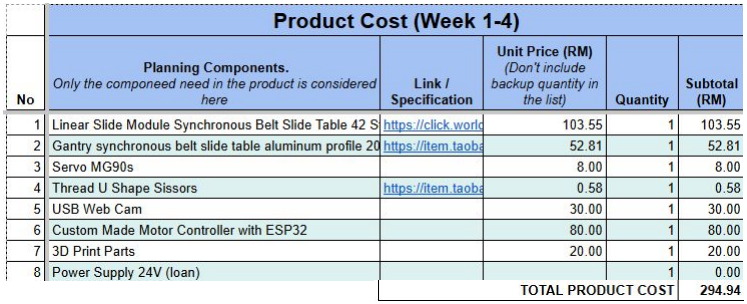
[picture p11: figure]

# S.T.E.E.P Analysis

Social

- Helps older farmers work more safely and easily.
- Reduces the need for many workers on the farm.

Technology

- Uses simple automation that’s easy to learn.
- Includes sensors and cameras for accurate fruit picking.

Economic

- Lowers labor and operation costs.
- Increases profit by improving harvest efficiency.

Environmental

- Reduces fruit waste by picking at the right time.
- Supports eco-friendly and careful farming methods.

Political/Legal

- Matches government goals for smart farming.
- May qualify for farming grants or support programs.

# Thank You

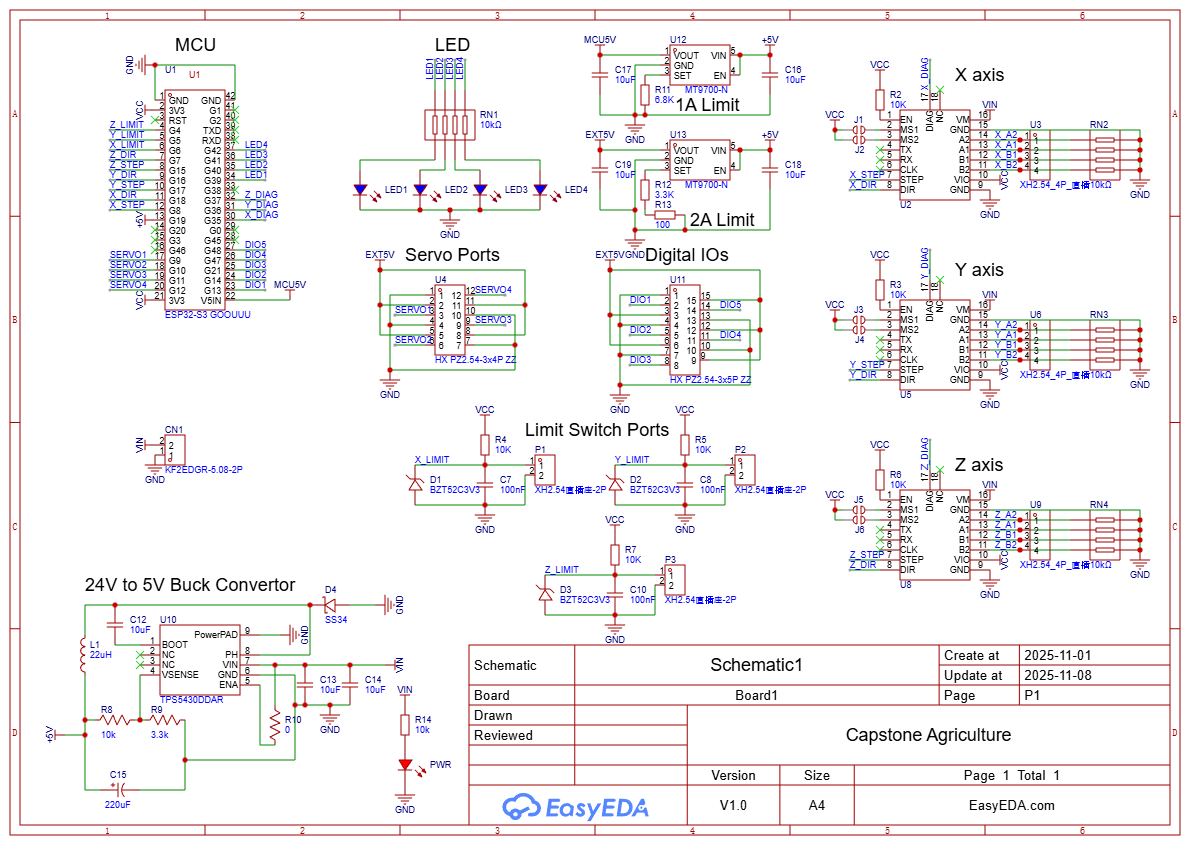
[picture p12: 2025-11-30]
PCB/SCH_Schematic1_1-P1_2025-11-21.png

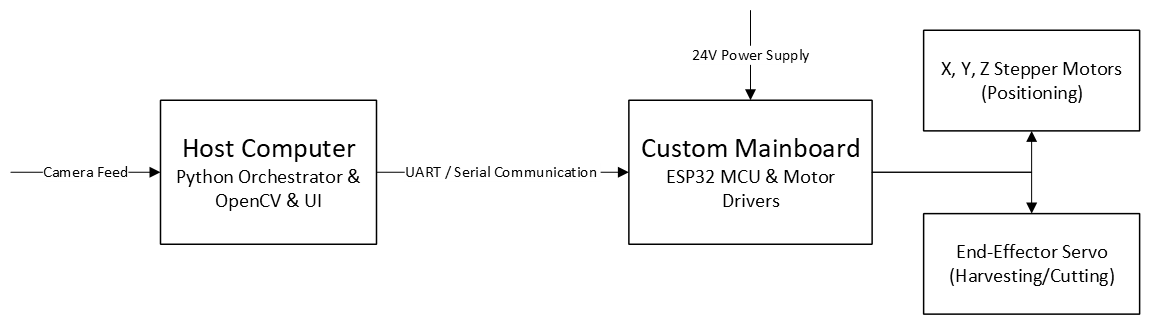
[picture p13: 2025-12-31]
Report/System Block Diagram.png

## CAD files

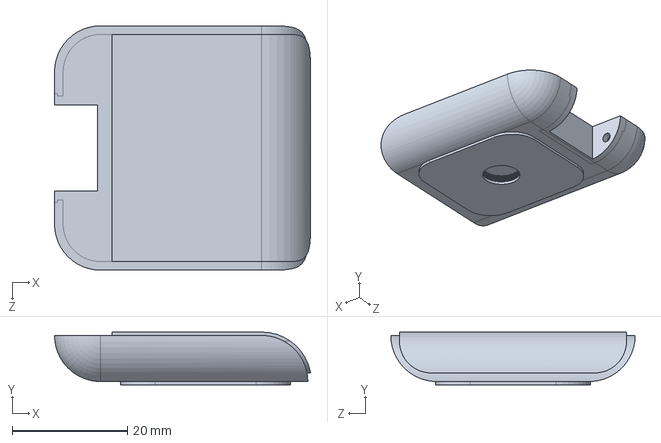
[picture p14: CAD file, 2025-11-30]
CAD/final assembly 1/Cam Base.SLDPRT
44.5 x 9.20 x 42.5 mm

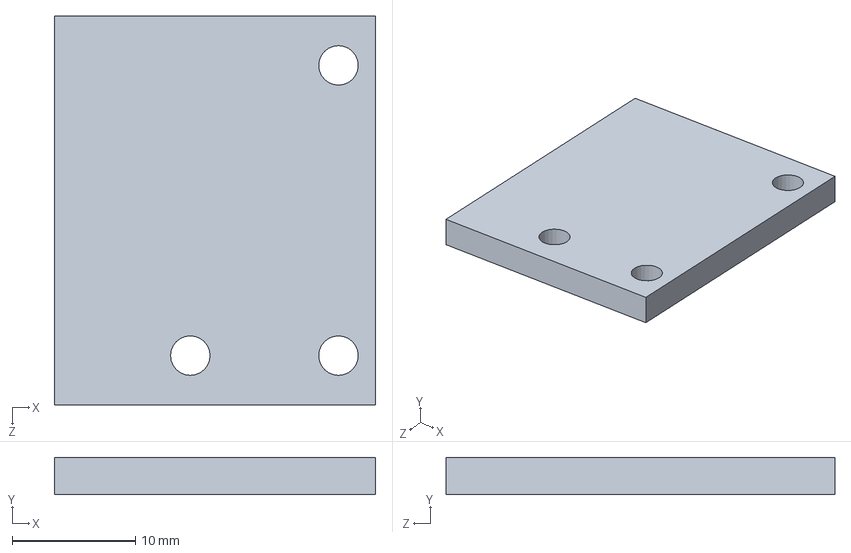
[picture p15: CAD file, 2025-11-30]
CAD/final assembly 1/ServoScissorHolderBottom.SLDPRT
26.0 x 3.00 x 31.5 mm

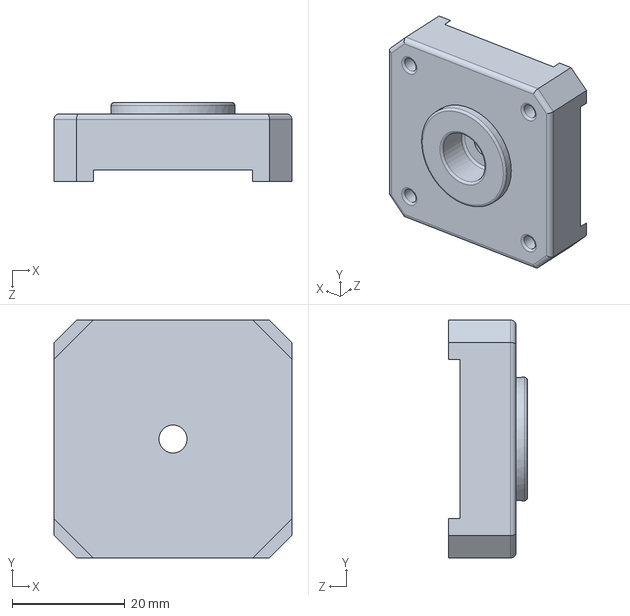
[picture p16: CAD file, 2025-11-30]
CAD/final assembly 1/backplate.SLDPRT
42.3 x 42.3 x 14.0 mm

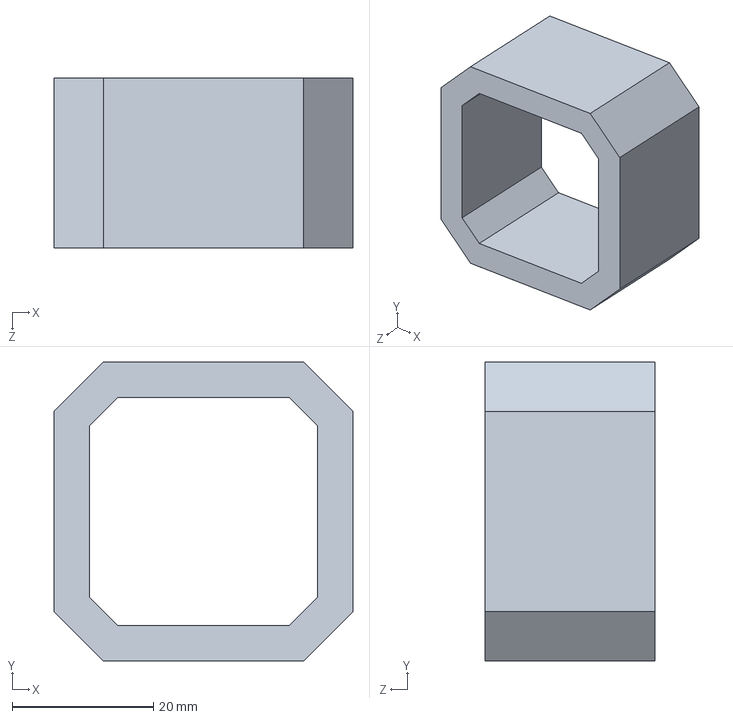
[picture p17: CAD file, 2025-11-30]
CAD/final assembly 1/Body.SLDPRT
42.3 x 42.3 x 24.0 mm

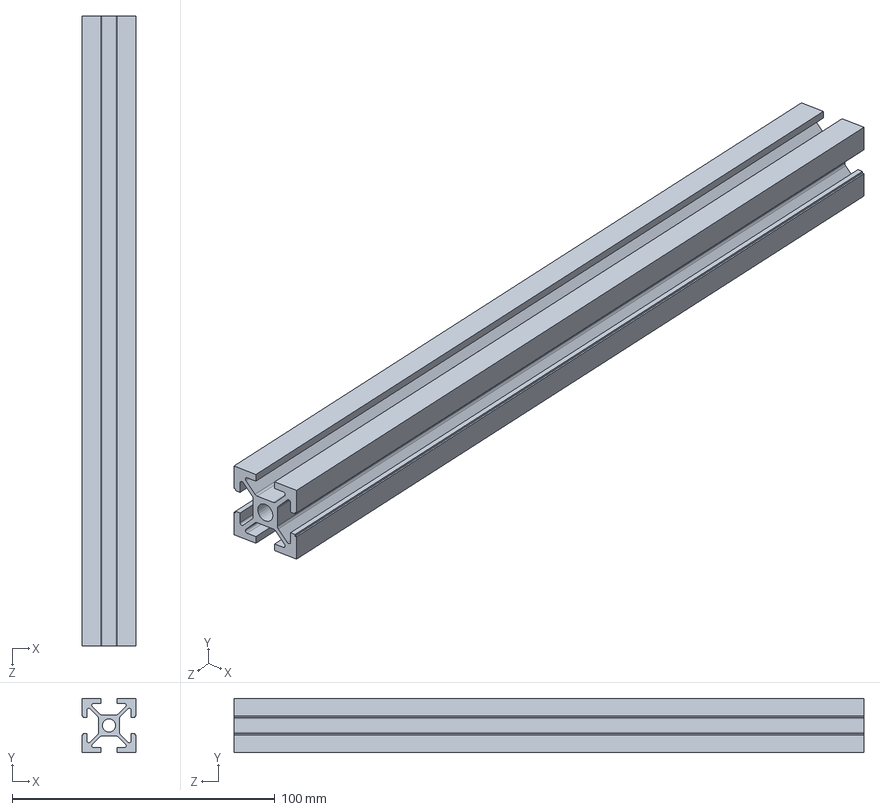
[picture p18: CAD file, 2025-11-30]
CAD/final assembly 1/aluminium profile 1.SLDPRT
20.7 x 20.7 x 240.0 mm

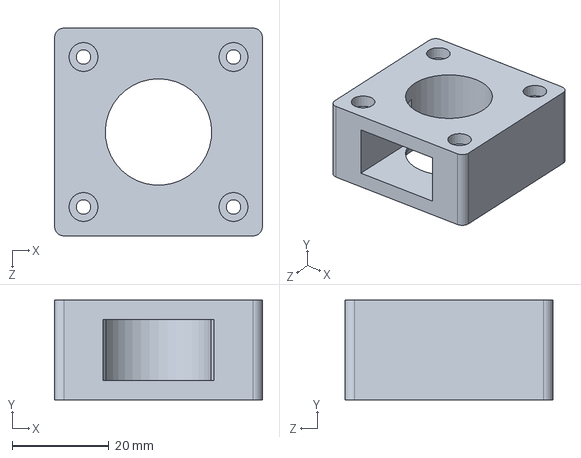
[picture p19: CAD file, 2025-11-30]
CAD/final assembly 1/stepper motor connector 1.SLDPRT
43.0 x 20.7 x 43.0 mm

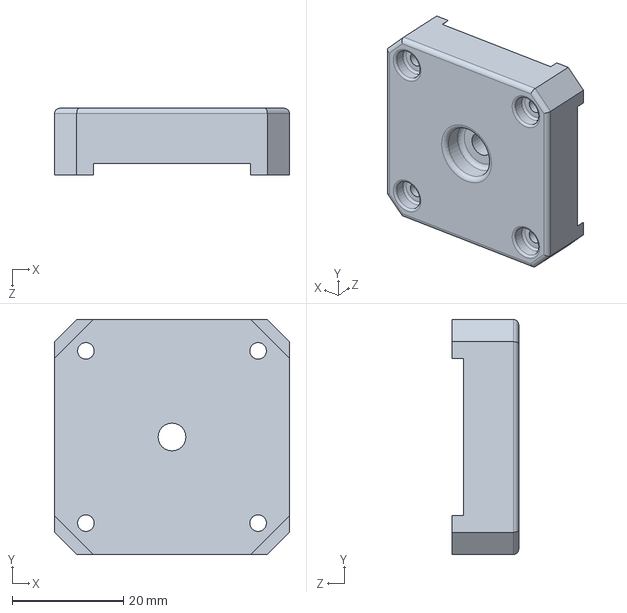
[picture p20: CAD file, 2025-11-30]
CAD/final assembly 1/Base.SLDPRT
42.3 x 42.3 x 12.0 mm

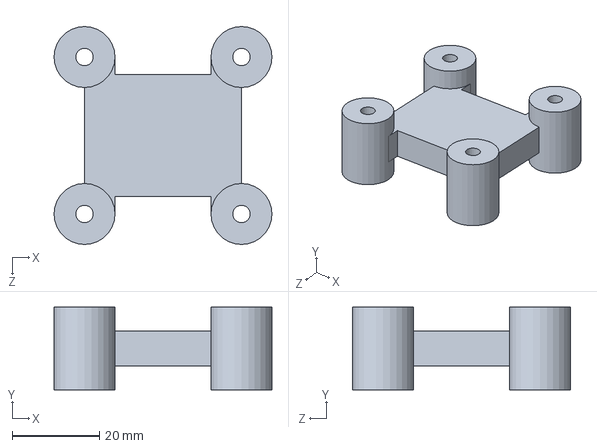
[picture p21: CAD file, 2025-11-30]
CAD/final assembly 1/x middle 1.SLDPRT
50.0 x 19.0 x 50.0 mm

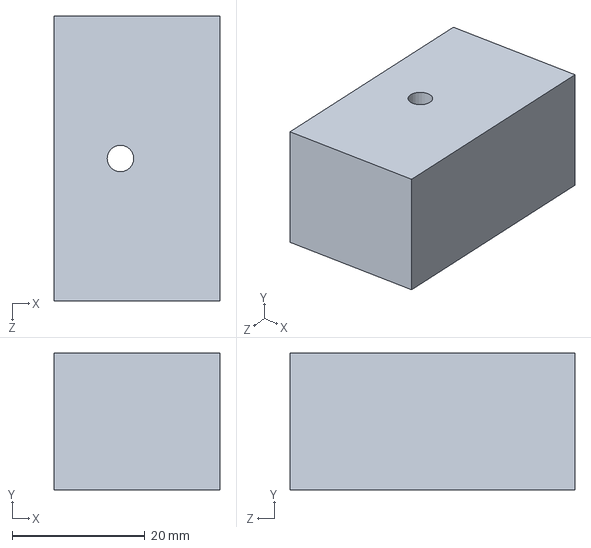
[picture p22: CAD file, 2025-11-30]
CAD/final assembly 1/x end 1.SLDPRT
25.0 x 20.7 x 43.0 mm

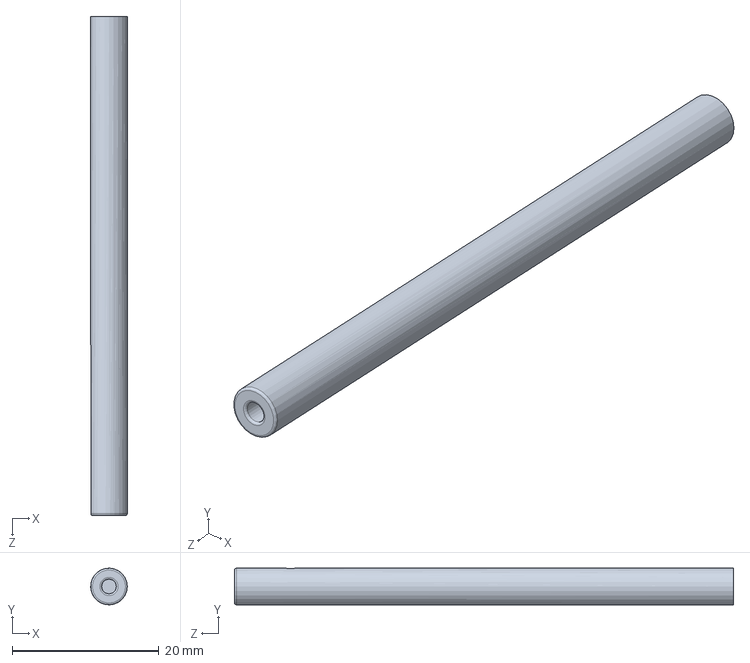
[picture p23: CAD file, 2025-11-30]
CAD/final assembly 1/Axial Rod.SLDPRT
5.00 x 5.00 x 68.0 mm

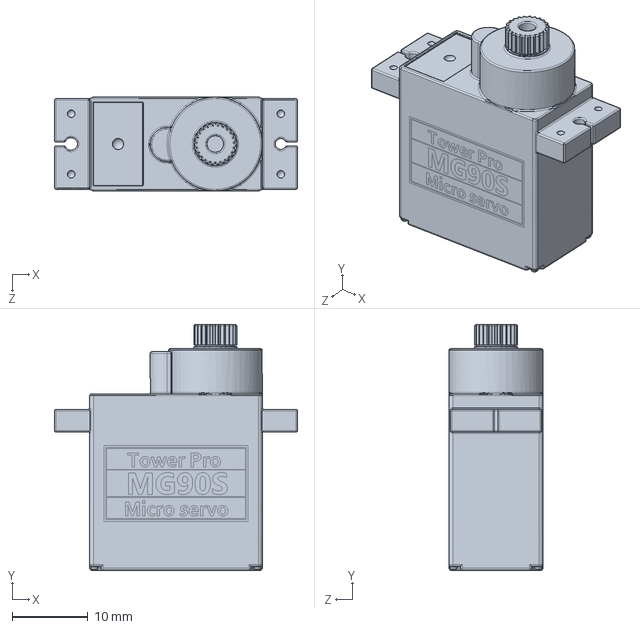
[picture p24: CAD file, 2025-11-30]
CAD/final assembly 1/Tower-Pro-MG90S.SLDPRT
32.1 x 32.5 x 12.4 mm

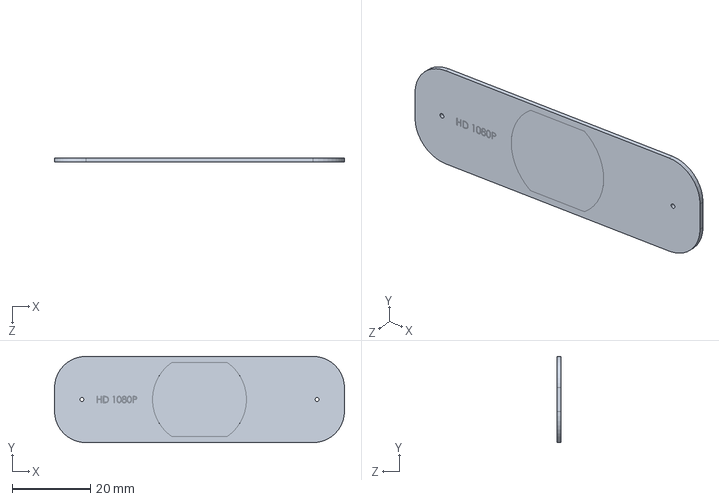
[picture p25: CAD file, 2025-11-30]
CAD/final assembly 1/Auto Focus HD 1080p Lens.SLDPRT
74.0 x 22.0 x 1.00 mm

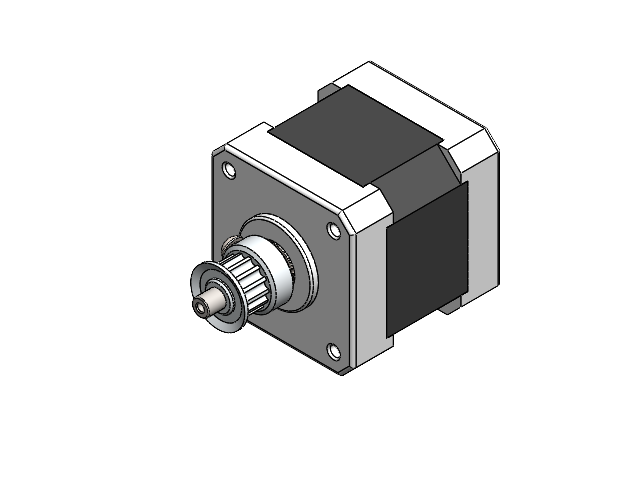
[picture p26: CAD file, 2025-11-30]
CAD/final assembly 1/Assem1_stepper_motor.SLDASM
Base
backplate
Axial Rod
instrument ball bearing_68_am x 2
pulley
socket button head cap screw_am
pan cross head_am x 4

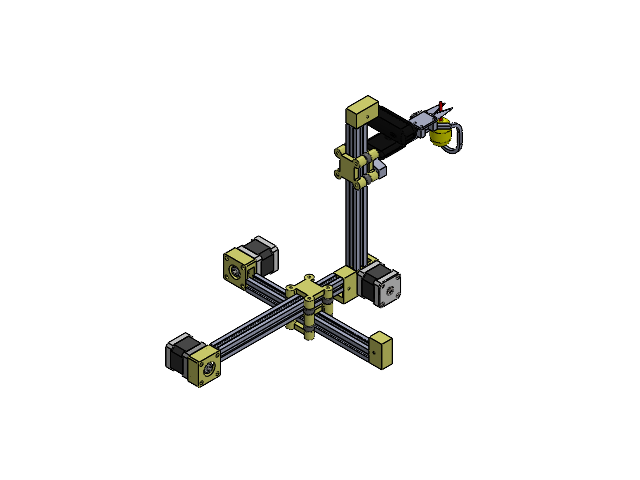
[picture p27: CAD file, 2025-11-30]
CAD/final assembly 1/final assembly 1.SLDASM
Base x 3
backplate x 3
Axial Rod x 3
instrument ball bearing_68_am x 6
pulley x 5
socket button head cap screw_am x 3
pan cross head_am x 12
stepper motor connector 1 x 3
aluminium profile 1
x end 1 x 3
x middle 1
bearing x 12
x middle 2 x 4
aluminium profile 2
aluminium profile 3
Tower-Pro-MG90S
UScissor x 2
Servohorn
ServoScissorHolderTop
ServoScissorHolderBottom
CutterHolder
Cam Base
Flexible Holder
Camera Casing
Auto Focus HD 1080p Lens
Lens Support
C260 WebCam
insert round nuts type a gb
Lemon

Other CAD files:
CAD/final assembly 1/Arm.SLDASM
CAD/final assembly 1/C260 WebCam Assembly.SLDASM
CAD/final assembly 1/aluminium profile 3.SLDPRT
CAD/final assembly 1/aluminium profile 2.SLDPRT
CAD/final assembly 1/C260 WebCam.SLDPRT
CAD/final assembly 1/Camera Casing.SLDPRT
CAD/final assembly 1/CutterHolder.SLDPRT
CAD/final assembly 1/Flexible Holder.SLDPRT
CAD/final assembly 1/Lemon.SLDPRT
CAD/final assembly 1/Lens Support.SLDPRT
CAD/final assembly 1/ServoScissorHolderTop.SLDPRT
CAD/final assembly 1/Servohorn.SLDPRT
CAD/final assembly 1/UScissor.SLDPRT
CAD/final assembly 1/bearing.SLDPRT
CAD/final assembly 1/pulley.SLDPRT
CAD/final assembly 1/x middle 2.SLDPRT

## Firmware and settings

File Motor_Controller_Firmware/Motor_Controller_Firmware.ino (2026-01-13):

#include <Arduino.h>
#include "Config.h"
#include "PinMap.h"
#include "LEDController.h"
#include "ServoController.h"
#include "StepperController.h"
#include "IOController.h"

// Instantiate Controllers
LEDController ledController;
ServoController servoController;
StepperController stepperController;
IOController ioController;

void setup() {
  Serial.begin(SERIAL_BAUD_RATE);
  while(!Serial) delay(10);
  Serial.println("Motor Controller Firmware Starting...");

  ledController.init();
  servoController.init();
  stepperController.init();
  ioController.init();

  // Initialize servo positions to neutral (90 degrees)
  servoController.write(0, 90);  // Cutter 1
  servoController.write(1, 90);  // Cutter 2
  servoController.write(2, 90);  // Gripper/Drop
  servoController.write(3, 90);  // Spare

  Serial.println("Initialization Complete.");
  Serial.println("Commands: M(ove) ?(status) !(stop) H(ome) S(ervo) C(ut) D(rop) L(ed) I(o) Z(limit)");
  
  ledController.blink(0, 500);
}

void processSerialCommand() {
  if (Serial.available() > 0) {
    char cmd = Serial.read();
    
    switch(cmd) {
      case 'L': // LED: L <index> <state>
        {
          int index = Serial.parseInt();
          int state = Serial.parseInt();
          ledController.set(index, state);
          Serial.printf("OK L %d %d\n", index, state);
        }
        break;
        
      case 'S': // Servo: S <index> <angle>
        {
          int index = Serial.parseInt();
          int angle = Serial.parseInt();
          servoController.write(index, angle);
          Serial.printf("OK S %d %d\n", index, angle);
        }
        break;
        
      case 'M': // Move Stepper (non-blocking): M <axis> <distance_mm> <speed> <accel>
        {
          int axis = Serial.parseInt();
          float distanceMM = Serial.parseFloat();
          float maxSpeed = Serial.parseFloat();
          float accel = Serial.parseFloat();
          
          if(maxSpeed <= 0) maxSpeed = StepperController::MAX_SPEED_MM_S;
          if(accel <= 0) accel = StepperController::MAX_ACCEL_MM_S2;

          stepperController.startMove((Axis)axis, distanceMM, maxSpeed, accel);
          Serial.printf("OK M %d %.2f\n", axis, distanceMM);
        }
        break;
        
      case 'B': // Blocking Move: B <axis> <distance_mm> <speed> <accel>
        {
          int axis = Serial.parseInt();
          float distanceMM = Serial.parseFloat();
          float maxSpeed = Serial.parseFloat();
          float accel = Serial.parseFloat();
          
          if(maxSpeed <= 0) maxSpeed = StepperController::MAX_SPEED_MM_S;
          if(accel <= 0) accel = StepperController::MAX_ACCEL_MM_S2;

          Serial.printf("BUSY M %d\n", axis);
          stepperController.moveMM((Axis)axis, distanceMM, maxSpeed, accel);
          Serial.printf("DONE %d\n", axis);
        }
        break;
        
      case '?': // STATUS - Query motor position and busy state
        {
          // Position
          Serial.printf("POS %.2f %.2f %.2f\n", 
            stepperController.getPositionMM(AXIS_X),
            stepperController.getPositionMM(AXIS_Y),
            stepperController.getPositionMM(AXIS_Z));
          // Busy state
          Serial.printf("BUSY %d %d %d\n",
            stepperController.isBusy(AXIS_X) ? 1 : 0,
            stepperController.isBusy(AXIS_Y) ? 1 : 0,
            stepperController.isBusy(AXIS_Z) ? 1 : 0);
        }
        break;
        
      case 'G': // CONFIG - Get axis limits
        {
          Serial.printf("LIMITS %.2f %.2f %.2f\n", 
            stepperController.getLimitMax(AXIS_X),
            stepperController.getLimitMax(AXIS_Y),
            stepperController.getLimitMax(AXIS_Z));
        }
        break;
        
      case '!': // Emergency stop
        {
          stepperController.stopAll();
          Serial.println("STOP");
        }
        break;
        
      case 'H': // SET ZERO - Reset position to 0,0,0 and lock motors
        {
          stepperController.homeAll();
          Serial.println("OK H");
        }
        break;
        
      case 'R': // UNLOCK - Disable steppers for manual movement
        {
          stepperController.disable();
          Serial.println("OK R");
        }
        break;
        
      case 'P': // Set position: P <axis> <position_mm>
        {
          int axis = Serial.parseInt();
          float pos = Serial.parseFloat();
          stepperController.setPositionMM((Axis)axis, pos);
          Serial.printf("OK P %d %.2f\n", axis, pos);
        }
        break;
        
      case 'W': // Set limits: W <axis> <min_mm> <max_mm>
        {
          int axis = Serial.parseInt();
          float minMM = Serial.parseFloat();
          float maxMM = Serial.parseFloat();
          stepperController.setLimits((Axis)axis, minMM, maxMM);
          Serial.printf("OK W %d %.2f %.2f\n", axis, minMM, maxMM);
        }
        break;
        
      case 'E': // Enable/disable limits: E <0|1>
        {
          int enable = Serial.parseInt();
          stepperController.enableLimits(enable != 0);
          Serial.printf("OK E %d\n", enable);
        }
        break;
        
      case 'I': // Read IO: I <index>
        {
          int index = Serial.parseInt();
          bool val = ioController.readDigital(index);
          Serial.printf("IO %d %d\n", index, val);
        }
        break;
        
      case 'Z': // Read Limit: Z <axis>
        {
          int axis = Serial.parseInt();
          bool val = ioController.readLimitSwitch(axis);
          Serial.printf("LIMIT %d %d\n", axis, val);
        }
        break;
        
      case 'C': // Cut sequence
        {
          int angle = Serial.parseInt();
          Serial.println("BUSY C");
          servoController.write(0, 90-angle);
          servoController.write(1, 90+angle);
          delay(300);
          servoController.write(0, 90);
          servoController.write(1, 90);
          delay(300);
          servoController.write(0, 90-angle);
          servoController.write(1, 90+angle);
          delay(300);
          servoController.write(0, 90);
          servoController.write(1, 90);
          delay(300);
          servoController.write(0, 90-angle);
          servoController.write(1, 90+angle);
          delay(300);
          servoController.write(0, 90);
          servoController.write(1, 90);
          delay(300);
          servoController.write(0, 90-angle);
          servoController.write(1, 90+angle);
          delay(300);
          servoController.write(0, 90);
          servoController.write(1, 90);
          delay(300);
          servoController.write(0, 90-angle);
          servoController.write(1, 90+angle);
          delay(300);
          servoController.write(0, 90);
          servoController.write(1, 90);
          Serial.println("OK C");
        }
        break;
        
      case 'D': // Drop sequence
        {
          int angle = Serial.parseInt();
          Serial.println("BUSY D");
          servoController.write(2, 90-angle);
          delay(1000);
          servoController.write(2, 90);
          Serial.println("OK D");
        }
        break;
    }
    
    // Clear remaining characters only until newline (preserve next command)
    while(Serial.available()) {
      char c = Serial.read();
      if (c == '\n' || c == '\r') break;  // Stop at end of this command
    }
  }
}

void loop() {
  ledController.update();
  stepperController.update();
  
  // --- LED Status Updates ---
  // LED 0: Heartbeat (set in setup)
  
  // LED 1: Moving/Action Indicator
  if (stepperController.isAnyBusy()) {
    ledController.set(1, HIGH);
  } else {
    ledController.set(1, LOW);
  }
  
  // LED 2: Ready/Home Indicator (All axes at 0)
  bool isHome = (stepperController.getPositionMM(AXIS_X) == 0 && 
                 stepperController.getPositionMM(AXIS_Y) == 0 && 
                 stepperController.getPositionMM(AXIS_Z) == 0);
  if (isHome) {
    ledController.set(2, HIGH);
  } else {
    ledController.set(2, LOW);
  }
  
  // LED 3: Limit/Error Warning
  bool atLimit = (stepperController.isAtLimit(AXIS_X) || 
                  stepperController.isAtLimit(AXIS_Y) || 
                  stepperController.isAtLimit(AXIS_Z));
  
  static bool wasAtLimit = false;
  if (atLimit && !wasAtLimit) {
    ledController.blink(3, 100); // Fast blink on error/limit
  } else if (!atLimit && wasAtLimit) {
    ledController.set(3, LOW);   // Off when safe
  }
  wasAtLimit = atLimit;
  // --------------------------
  
  // Check for move completions and report
  for(int i = 0; i < 3; i++) {
    if(stepperController.checkCompleted((Axis)i)) {
      Serial.printf("DONE %d\n", i);
    }
  }
  
  processSerialCommand();
}

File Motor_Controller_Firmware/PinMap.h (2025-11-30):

#ifndef PINMAP_H
#define PINMAP_H

#include <Arduino.h>

// --- Onboard LEDs (4) ---
// Update these pins according to your custom board layout
#define PIN_LED_1  39
#define PIN_LED_2  40
#define PIN_LED_3  41
#define PIN_LED_4  42

// --- Servos (4) ---
#define PIN_SERVO_1 9
#define PIN_SERVO_2 10
#define PIN_SERVO_3 11
#define PIN_SERVO_4 12

// --- Steppers (X, Y, Z) ---
// TMC2209 UART Pins (SoftwareSerial or HardwareSerial)
// Assuming separate UART pins or shared single wire UART. 
// If using HardwareSerial, define RX/TX.
#define PIN_TMC_RX 2
#define PIN_TMC_TX 1

#define PIN_EN    20
// X Axis
#define PIN_STEP_X  8
#define PIN_DIR_X   18

// Y Axis
#define PIN_STEP_Y  17
#define PIN_DIR_Y   16

// Z Axis
#define PIN_STEP_Z  15
#define PIN_DIR_Z   7

// --- Limit Switches (Mapped to IO pins for now) ---
#define PIN_LIMIT_X PIN_IO_1
#define PIN_LIMIT_Y PIN_IO_2
#define PIN_LIMIT_Z PIN_IO_3

// --- Digital IOs (5) ---
#define PIN_IO_1    13
#define PIN_IO_2    14
#define PIN_IO_3    21
#define PIN_IO_4    47
#define PIN_IO_5    48

#endif // PINMAP_H

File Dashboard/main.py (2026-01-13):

"""
Motor Controller Dashboard - Main Application
"""

import customtkinter as ctk
import cv2
import serial
import serial.tools.list_ports
import threading
import time

from camera import CameraThread, DetectionThread
from harvester import HarvestState, HarvestingStateMachine
from embedded_cv_display import EmbeddedCVDisplay


class DashboardApp(ctk.CTk):
    def __init__(self):
        super().__init__()

        self.title("Motor Controller Dashboard")
        self.geometry("1366x768")

        # Fullscreen
        self.after(0, lambda: self.state("zoomed"))
        self.bind("<Escape>", lambda e: self.destroy())

        ctk.set_appearance_mode("Dark")
        ctk.set_default_color_theme("blue")

        # Serial Connection
        self.serial_port = None
        self.is_connected = False

        # Camera and Detection Threads (decoupled)
        self.camera_thread = CameraThread(
            mock_mode=False, mock_path="mock_lemon.mp4", target_fps=30
        )
        self.detection_thread = DetectionThread(self.camera_thread.frame_buffer)

        self.camera_thread.start()
        self.detection_thread.start()

        self.selected_lemon_id = None
        self.detected_lemons = []
        self.lemon_buttons = {}

        # Harvesting State Machine
        self.harvester = HarvestingStateMachine(self)

        # Layout Configuration - fixed width right panel
        self.grid_columnconfigure(0, weight=1)
        self.grid_columnconfigure(1, weight=0, minsize=420)
        self.grid_rowconfigure(0, weight=1)

        # Left Frame: Camera (container for embedded OpenCV window)
        self.camera_frame = ctk.CTkFrame(self)
        self.camera_frame.grid(row=0, column=0, padx=5, pady=5, sticky="nsew")

        # Embedded OpenCV display (native performance)
        self.cv_display = EmbeddedCVDisplay(self.camera_frame, "Camera Feed")

        # Right Frame: Controls (fixed, no scroll)
        self.controls_frame = ctk.CTkFrame(self, width=420)
        self.controls_frame.grid(row=0, column=1, padx=5, pady=5, sticky="nsew")
        self.controls_frame.grid_propagate(False)

        self.setup_controls()

        # Polling Thread
        self.polling = False
        self.poll_thread = None

        # Start UI Update Loop (delay to ensure window is realized)
        self.after(500, self.update_camera_ui)

    def setup_controls(self):
        """Setup control panel with clean, organized layout."""
        # Configure grid - log box expands
        self.controls_frame.grid_columnconfigure(0, weight=1)
        self.controls_frame.grid_rowconfigure(5, weight=1)

        row = 0
        pad_x, pad_y = 8, 4

        # ===== SECTION 1: Connection =====
        conn_section = ctk.CTkFrame(self.controls_frame)
        conn_section.grid(row=row, column=0, padx=pad_x, pady=(pad_y, 2), sticky="ew")
        row += 1

        # Title bar with status
        title_row = ctk.CTkFrame(conn_section, fg_color="transparent")
        title_row.pack(fill="x", padx=5, pady=(5, 2))
        ctk.CTkLabel(
            title_row,
            text="CONNECTION",
            font=("Arial", 11, "bold"),
            text_color="#888888",
        ).pack(side="left")
        self.harvest_status_label = ctk.CTkLabel(
            title_row, text="IDLE", font=("Arial", 11, "bold"), text_color="#00FF00"
        )
        self.harvest_status_label.pack(side="right")

        # Connection controls
        conn_row = ctk.CTkFrame(conn_section, fg_color="transparent")
        conn_row.pack(fill="x", padx=5, pady=(0, 5))

        self.port_combo = ctk.CTkComboBox(
            conn_row, values=self.get_serial_ports(), width=110
        )
        self.port_combo.pack(side="left", padx=(0, 3))

        self.refresh_btn = ctk.CTkButton(
            conn_row, text="↻", width=28, command=self.refresh_ports
        )
        self.refresh_btn.pack(side="left", padx=2)

        self.connect_btn = ctk.CTkButton(
            conn_row, text="Connect", width=65, command=self.toggle_connection
        )
        self.connect_btn.pack(side="left", padx=2)

        self.stop_btn = ctk.CTkButton(
            conn_row,
            text="E-STOP",
            width=55,
            fg_color="#CC0000",
            hover_color="#990000",
            font=("Arial", 11, "bold"),
            command=self.emergency_stop,
        )
        self.stop_btn.pack(side="right")

        # ===== SECTION 2: Detected Lemons =====
        lemon_section = ctk.CTkFrame(self.controls_frame)
        lemon_section.grid(row=row, column=0, padx=pad_x, pady=2, sticky="ew")
        row += 1

        ctk.CTkLabel(
            lemon_section,
            text="TARGETS",
            font=("Arial", 11, "bold"),
            text_color="#888888",
        ).pack(anchor="w", padx=5, pady=(5, 2))

        self.lemon_list_container = ctk.CTkScrollableFrame(lemon_section, height=75)
        self.lemon_list_container.pack(fill="x", padx=5, pady=(0, 5))

        # ===== SECTION 3: Harvest Control =====
        harvest_section = ctk.CTkFrame(self.controls_frame)
        harvest_section.grid(row=row, column=0, padx=pad_x, pady=2, sticky="ew")
        row += 1

        ctk.CTkLabel(
            harvest_section,
            text="HARVEST",
            font=("Arial", 11, "bold"),
            text_color="#888888",
        ).pack(anchor="w", padx=5, pady=(5, 2))

        # Main harvest buttons
        harvest_btns = ctk.CTkFrame(harvest_section, fg_color="transparent")
        harvest_btns.pack(fill="x", padx=5, pady=2)
        harvest_btns.grid_columnconfigure((0, 1, 2), weight=1)

        ctk.CTkButton(
            harvest_btns,
            text="▶ HARVEST",
            height=34,
            fg_color="#228B22",
            hover_color="#1a6b1a",
            font=("Arial", 12, "bold"),
            command=self.start_harvest,
        ).grid(row=0, column=0, padx=2, sticky="ew")

        ctk.CTkButton(
            harvest_btns,
            text="▶▶ AUTO",
            height=34,
            fg_color="#1976D2",
            hover_color="#1565C0",
            font=("Arial", 12, "bold"),
            command=self.start_auto_harvest,
        ).grid(row=0, column=1, padx=2, sticky="ew")

        ctk.CTkButton(
            harvest_btns,
            text="■ ABORT",
            height=34,
            fg_color="#C62828",
            hover_color="#B71C1C",
            font=("Arial", 12, "bold"),
            command=self.abort_harvest,
        ).grid(row=0, column=2, padx=2, sticky="ew")

        # Offset controls (smaller)
        offset_row = ctk.CTkFrame(harvest_section, fg_color="transparent")
        offset_row.pack(fill="x", padx=5, pady=(2, 5))
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

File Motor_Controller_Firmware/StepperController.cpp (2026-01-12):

#include "StepperController.h"
#include "PinMap.h"
#include "Config.h"
#include <stdlib.h>
#include <math.h>

#define TMC_SERIAL Serial2 

StepperController::StepperController() {
    _stepPins[AXIS_X] = PIN_STEP_X;
    _dirPins[AXIS_X] = PIN_DIR_X;

    _stepPins[AXIS_Y] = PIN_STEP_Y;
    _dirPins[AXIS_Y] = PIN_DIR_Y;

    _stepPins[AXIS_Z] = PIN_STEP_Z;
    _dirPins[AXIS_Z] = PIN_DIR_Z;
    
    _enPin = PIN_EN;
    
    // Initialize position tracking and limits
    _limitsEnabled = true;
    for(int i = 0; i < 3; i++) {
        _positionMM[i] = 0.0;
        _motion[i].active = false;
        _motion[i].completed = false;
    }
    
    // Default soft limits per axis (adjust to your machine dimensions)
    _limitMin[AXIS_X] = 0.0;    _limitMax[AXIS_X] = 130.0;  // X: 0 to 300mm
    _limitMin[AXIS_Y] = 0.0;    _limitMax[AXIS_Y] = 230.0;  // Y: 0 to 300mm  
    _limitMin[AXIS_Z] = 0.0;    _limitMax[AXIS_Z] = 130.0;  // Z: 0 to 100mm (shorter)
}

void StepperController::init() {
    pinMode(_enPin, OUTPUT);
    digitalWrite(_enPin, LOW); // Enable by default
    
    for(int i = 0; i < 3; i++) {
        pinMode(_stepPins[i], OUTPUT);
        pinMode(_dirPins[i], OUTPUT);
    }
}

void StepperController::enable() {
    digitalWrite(_enPin, LOW);
}

void StepperController::disable() {
    digitalWrite(_enPin, HIGH);
}

void StepperController::setDirection(Axis axis, bool dir) {
    digitalWrite(_dirPins[axis], dir ? HIGH : LOW);
}

void StepperController::step(Axis axis) {
    digitalWrite(_stepPins[axis], HIGH);
    delayMicroseconds(2);
    digitalWrite(_stepPins[axis], LOW);
}

// Calculate delay based on acceleration profile
float StepperController::calculateDelay(long stepNum, long accelSteps, long totalSteps, float minDelay, float accelMM_s2) {
    float currentSpeed;
    
    if (stepNum < accelSteps) {
        // ACCELERATION phase
        currentSpeed = sqrt(2.0 * (accelMM_s2 * STEPS_PER_MM) * (stepNum + 1));
    } 
    else if (stepNum >= totalSteps - accelSteps) {
        // DECELERATION phase
        long stepsRemaining = totalSteps - stepNum;
        currentSpeed = sqrt(2.0 * (accelMM_s2 * STEPS_PER_MM) * stepsRemaining);
    } 
    else {
        // CONSTANT SPEED phase
        return minDelay;
    }
    
    float delay = 1000000.0 / currentSpeed;
    if (delay > 20000) delay = 20000;  // Safety clamp
    if (delay < minDelay) delay = minDelay;
    return delay;
}

// Start a non-blocking move
void StepperController::startMove(Axis axis, float distanceMM, float maxSpeedMM_s, float accelMM_s2) {
    // Apply defaults if needed
    if (maxSpeedMM_s <= 0) maxSpeedMM_s = MAX_SPEED_MM_S;
    if (accelMM_s2 <= 0) accelMM_s2 = MAX_ACCEL_MM_S2;
    
    long steps = (long)(distanceMM * STEPS_PER_MM);
    if (steps == 0) return;
    
    MotionState& m = _motion[axis];
    
    m.direction = steps > 0;
    m.targetSteps = abs(steps);
    m.currentStep = 0;
    m.completed = false;
    
    // Set direction
    setDirection(axis, m.direction);
    
    // Calculate acceleration steps
    m.accelSteps = (long)((maxSpeedMM_s * maxSpeedMM_s * STEPS_PER_MM * STEPS_PER_MM) / (2.0 * accelMM_s2 * STEPS_PER_MM));
    if (m.accelSteps > m.targetSteps / 2) {
        m.accelSteps = m.targetSteps / 2;
    }
    
    // Calculate min delay (at max speed)
    m.minDelay = 1000000.0 / (maxSpeedMM_s * STEPS_PER_MM);
    
    // Calculate initial delay
    m.currentDelay = calculateDelay(0, m.accelSteps, m.targetSteps, m.minDelay, accelMM_s2);
    
    m.lastStepTime = micros();
    m.active = true;
}

// Process non-blocking motion for all axes (call in loop)
void StepperController::update() {
    unsigned long now = micros();
    
    for (int i = 0; i < 3; i++) {
        MotionState& m = _motion[i];
        
        if (!m.active) continue;
        
        // Check if enough time has passed for next step
        if (now - m.lastStepTime >= (unsigned long)m.currentDelay) {
            // Take a step
            step((Axis)i);
            m.currentStep++;
            m.lastStepTime = now;
            
            // Update position tracking
            float stepMM = 1.0 / STEPS_PER_MM;
            if (m.direction) {
                _positionMM[i] += stepMM;
            } else {
                _positionMM[i] -= stepMM;
            }
            
            // Check if move complete
            if (m.currentStep >= m.targetSteps) {
                m.active = false;
                m.completed = true;
            } else {
                // Check soft limits
                if (_limitsEnabled) {
                    if (_positionMM[i] <= _limitMin[i] || _positionMM[i] >= _limitMax[i]) {
                        m.active = false;
                        m.completed = true;
                        Serial.printf("LIMIT %d %.2f\n", i, _positionMM[i]);
                    }
                }
                
                // Calculate next delay
                m.currentDelay = calculateDelay(m.currentStep, m.accelSteps, m.targetSteps, m.minDelay, MAX_ACCEL_MM_S2);
            }
        }
    }
}

// Legacy blocking move (for compatibility)
void StepperController::moveMM(Axis axis, float distanceMM, float maxSpeedMM_s, float accelMM_s2) {
    startMove(axis, distanceMM, maxSpeedMM_s, accelMM_s2);
    
    // Block until complete
    while (_motion[axis].active) {
        update();
    }
}

bool StepperController::isBusy(Axis axis) {
    return _motion[axis].active;
}

bool StepperController::isAnyBusy() {
    return _motion[AXIS_X].active || _motion[AXIS_Y].active || _motion[AXIS_Z].active;
}

bool StepperController::checkCompleted(Axis axis) {
    if (_motion[axis].completed) {
        _motion[axis].completed = false;  // Clear flag
        return true;
    }
    return false;
}

float StepperController::getPositionMM(Axis axis) {
    return _positionMM[axis];
}

void StepperController::setPositionMM(Axis axis, float pos) {
    _positionMM[axis] = pos;
}

void StepperController::homeAll() {
    stopAll();
    enable();  // Re-enable motors
    for (int i = 0; i < 3; i++) {
        _positionMM[i] = 0.0;
    }
}

void StepperController::stopAll() {
    for (int i = 0; i < 3; i++) {
        stopAxis((Axis)i);
    }
}

void StepperController::stopAxis(Axis axis) {
    _motion[axis].active = false;
    _motion[axis].completed = false;
}

void StepperController::setLimits(Axis axis, float minMM, float maxMM) {
    _limitMin[axis] = minMM;
    _limitMax[axis] = maxMM;
}

void StepperController::enableLimits(bool enable) {
    _limitsEnabled = enable;
}

bool StepperController::isAtLimit(Axis axis) {
    return _positionMM[axis] <= _limitMin[axis] || _positionMM[axis] >= _limitMax[axis];
}

float StepperController::getLimitMax(Axis axis) {
    return _limitMax[axis];
}

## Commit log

2025-11-30 feat: Add initial CAD, PCB, firmware, and documentation files for the Capstone project.
    [Arm.SLDASM, Assem1_stepper_motor.SLDASM, Auto Focus HD 1080p Lens.SLDPRT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]
2025-11-30 feat: Implement core motor controller firmware with modules for LED, Servo, Stepper, and IO control.
2025-12-31 feat: Add motor controller firmware with serial command interface and a dashboard with camera feed and lemon detection.
2026-01-12 feat: Add Kalman tracking, visual servo control, and auto-harvest mode
    - Add Kalman filter tracking for smooth lemon position estimation
    - Add multi-threaded camera capture with triple-buffered FrameBuffer
    - Add HarvestingStateMachine with visual servo control and 5 states
    - Add EmbeddedCVDisplay for native OpenCV rendering in Tkinter (60 FPS)
    - Add auto-harvest mode for consecutive lemon harvesting
    - Update firmware with non-blocking motor control and soft limits
    - Update README files with correct HSV values (H: 10-30, V: 40-255)
    - Add .gitignore for Python, IDE, and build artifacts
    [Motor_Controller_Firmware.ino, StepperController.cpp, camera.py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]
2026-01-12 docs: Add Technical Report and reorganize project files
    - Add Technical_Report.txt with complete project documentation
    - Move Discussion Note to Report folder
    - Update Rules & Rubric to v9
    - Update .gitignore to track Report folder (except private files)
    - Fix HSV values in documentation (H: 10-30, V: 40-255)
2026-01-12 docs: Update READMEs with accurate technical specifications
    - Fix occlusion tolerance: 3 seconds (90 frames) not 2 seconds
    - Add Technical Specifications table to main README
    - Add harvester parameters: max_frames_lost, max_correction, cutter offsets
    - Add GPIO pin assignments table to firmware README
    - Add Config.h constants table to firmware README
2026-01-12 chore: Add .gitattributes to fix GitHub language detection
    - Mark PCB Interactive BOM HTML as linguist-generated (18MB file)
    - Mark CAD files as vendored (not code)
    - Mark PDFs and images as documentation
    - This fixes GitHub showing 99.4% HTML instead of actual code languages
2026-01-13 Enhance Dashboard UI and Harvester Logic - Redesigned control panel for better layout at 125% scaling (1366x768) - Fixed button overflow using grid layout for motor/harvest controls - Implemented rob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
    [Motor_Controller_Firmware.ino, harvester.py, main.py]
